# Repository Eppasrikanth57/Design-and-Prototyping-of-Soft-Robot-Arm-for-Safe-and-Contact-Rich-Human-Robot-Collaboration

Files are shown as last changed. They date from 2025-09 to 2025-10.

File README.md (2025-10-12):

# Design-and-Prototyping-of-Soft-Robot-Arm-for-Safe-and-Contact-Rich-Human-Robot-Collaboration
This repository contains the CAD designs, STL models, and embedded control code developed for my Master’s thesis at Hochschule Schmalkalden, Germany.
The project focuses on designing, building, and experimentally validating a vacuum-actuated soft robotic arm capable of safe, contact-rich human–robot collaboration.

The soft robotic arm is designed with modular flexible structures, granular-jamming-based variable stiffness, and multi-sensor feedback (force, proximity, and strain sensing). It offers a novel approach for achieving inherent safety in close human–robot interaction, aligning with the Industry 5.0 vision of human-centered manufacturing.

## 📁 Repository Structure

```bash
├── 2D Drawings/           # Technical manufacturing drawings of soft arm components  
├── 3D CAD files/          # 3D part and assembly models designed in SolidWorks 2022 and 2024  
├── Coding/                # Arduino control code for actuation, sensing, and vacuum control  
├── STL/                   # Exported STL files for 3D printing of structural components  
├── LICENSE                # MIT License for academic and research use  
└── README.md              # Project overview file
```

## 🛠️ Project Description

This thesis presents the complete design, prototyping, and validation of a motorized and vacuum-actuated soft robotic arm that dynamically changes stiffness using a Venturi-effect vacuum generator.
The system integrates force-sensing resistors (FSRs), time-of-flight (ToF) sensors, and foil strain gauges to perceive environmental interactions and respond safely to human contact.

## Key Highlights:

Vacuum-Actuated Variable Stiffness:
Uses granular jamming via a Venturi-based vacuum generator to switch between soft and rigid modes.

Soft Structure & Additive Manufacturing:
Arm links and mounts fabricated using 3D printing and elastomeric materials for modularity and flexibility.

Multi-Sensor Integration:
Embedded FSRs, ToF sensors, and strain gauges enable adaptive response and safety behavior.

Microcontroller-Based Control:
An Arduino Mega 2560 manages pneumatic valves, sensors, and control logic for real-time adaptability.

Human-Robot Safety Compliance:
Experimental results confirm impact forces remain within ISO/TS 15066 biomechanical safety limits.

## 💻 Code Overview

The Coding/ folder includes Arduino programs written for system control and sensor integration.

### Included functionalities:

Actuation control using low-power solenoid valves

Venturi vacuum generation for stiffness modulation

Real-time force and proximity sensing

Safety logic to reduce stiffness upon human approach

### Hardware interfacing includes:

Arduino Mega 2560

Festo MYH-5/3G-M5-L-LED solenoid valves

ELEGOO 5V relay module

VL53LXX-V2 ToF sensor

Force-Sensitive Resistors and Strain Gauges

## ⚙️ Experimental Validation

The system was tested through multiple experiments:

Impact Tests: Collision safety assessment with varying vacuum pressures and bead fillings.

Tension Tests: Force-displacement behavior for soft and stiff states.

Comparative Tests: Impact forces benchmarked against a UR5e collaborative robot, confirming improved safety.

The prototype demonstrated smooth transition between compliant and stiff modes, validating its effectiveness for safe, contact-rich human interaction.

## 🧩 CAD and STL Files

3D CAD files/: Solidworks models for soft arm prototypes, vacuum connectors, mounts, and baffles.

STL/: Printable versions of structural and interface components for 3D printing.

2D Drawings/: Engineering drawings with manufacturing dimensions and tolerances.

## 🔬 Applications

Human–Robot Collaboration (HRC)

Industrial manipulation and assembly

Healthcare and assistive robotics

Research and educational platforms

Service and domestic robotics

## 🧠 Research Focus

This repository supports research into:

Safe and adaptive soft robotic manipulators

Vacuum-based variable stiffness mechanisms

Multi-sensor fusion for human-aware robot control

Design methodologies for Industry 5.0 systems

## 🖌️ Licensing

This project is released under the MIT License.
All contents are free to use for academic, research, and personal learning purposes.
Commercial use requires prior written permission.

## 👨‍🎓 Author

Srikanth Reddy Eppa  
M.Eng. Mechatronics and Robotics  
Hochschule Schmalkalden, Germany

## 📧 Contact:  
For academic inquiries, feedback, or collaboration, feel free to reach out via [LinkedIn](https://www.linkedin.com/in/srikanth-reddy-eppa/) or contact through university channels.

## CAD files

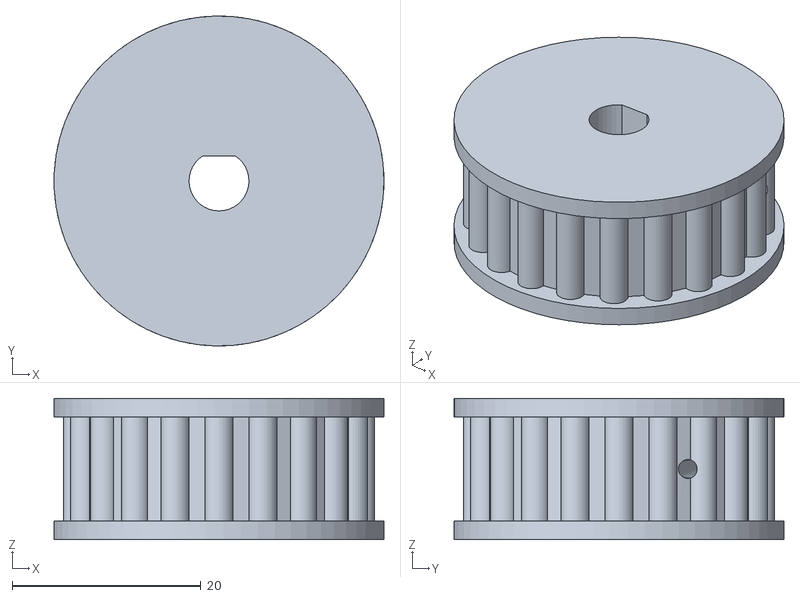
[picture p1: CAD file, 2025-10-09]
STL/Pulley.STL
35.0 x 35.0 x 15.0

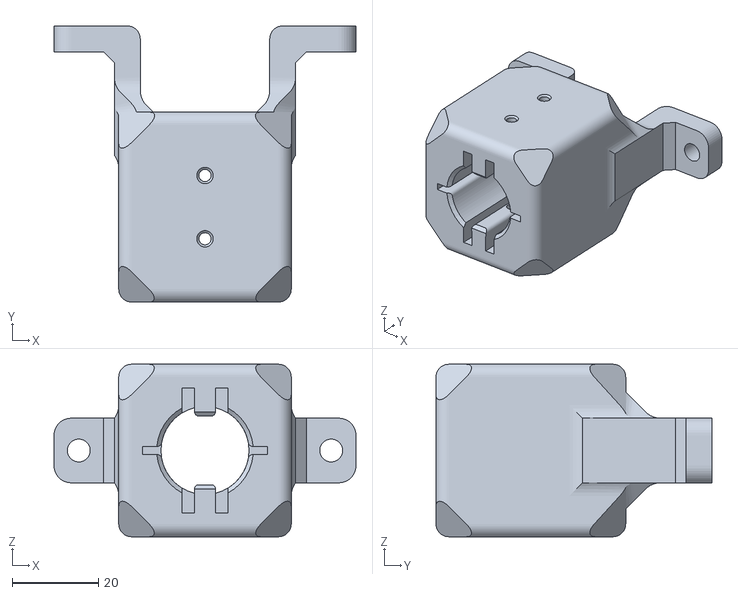
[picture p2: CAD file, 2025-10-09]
STL/Gripper mount v4.STL
70.0 x 64.0 x 40.0

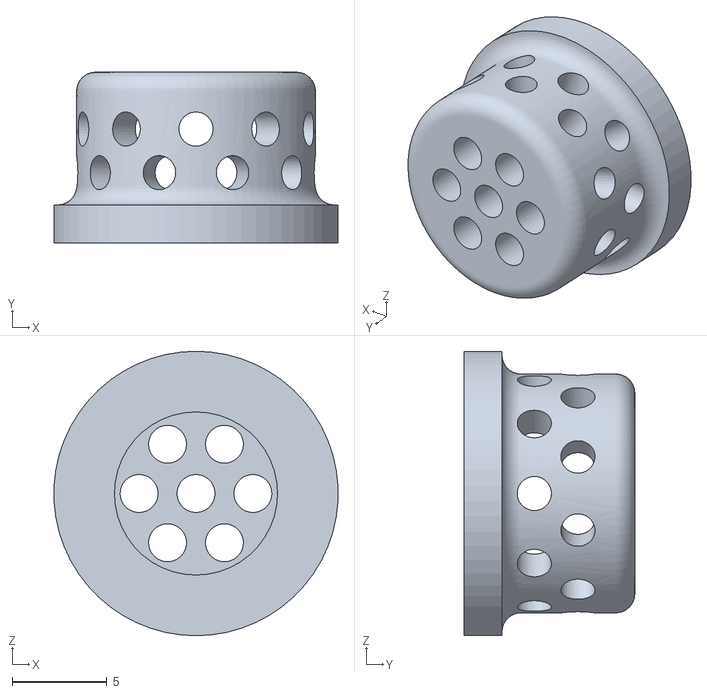
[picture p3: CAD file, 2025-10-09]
STL/Mesh.STL
15.0 x 9.00 x 15.0

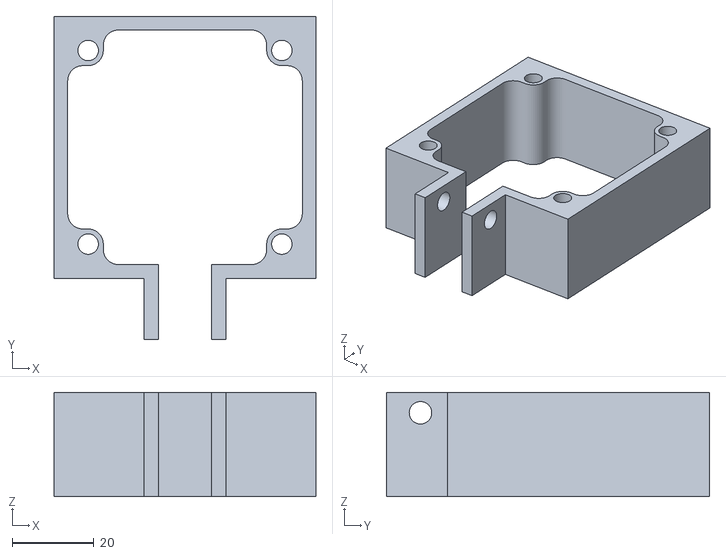
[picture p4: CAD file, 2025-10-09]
STL/Nema 23 clamp.STL
64.0 x 79.0 x 25.5

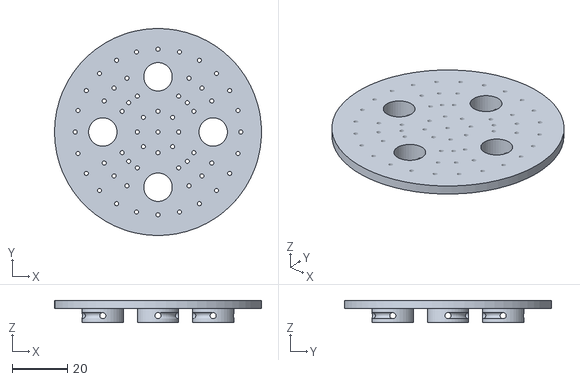
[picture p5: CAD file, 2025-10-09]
STL/Baffle plate.STL
75.0 x 75.0 x 8.00

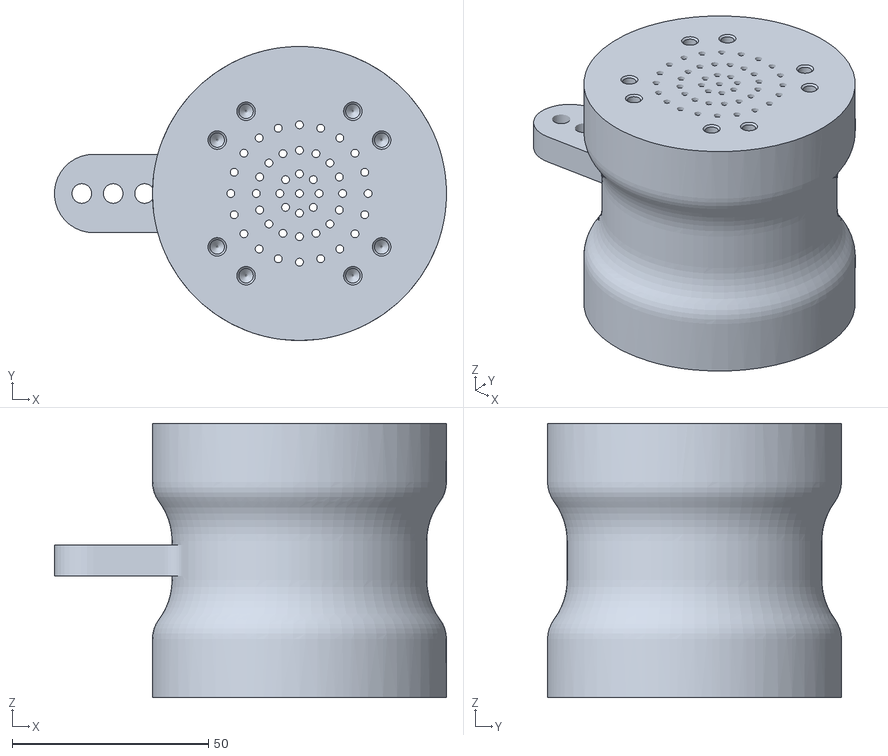
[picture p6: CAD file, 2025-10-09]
STL/Middle cylinder vacuum control test V1.STL
100.0 x 75.0 x 70.0

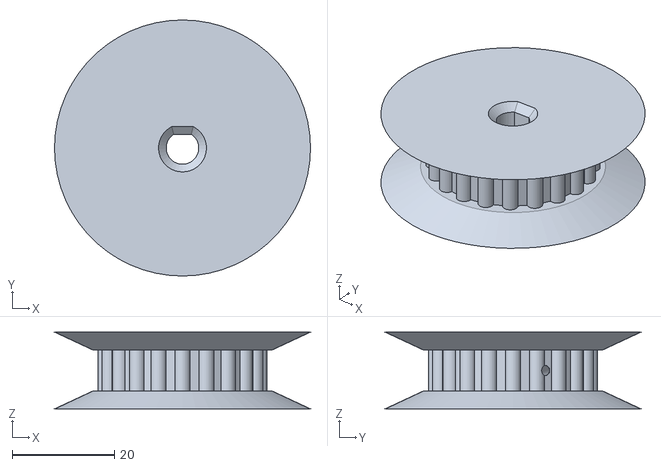
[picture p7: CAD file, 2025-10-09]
STL/Pulley V2.STL
50.0 x 50.0 x 15.0

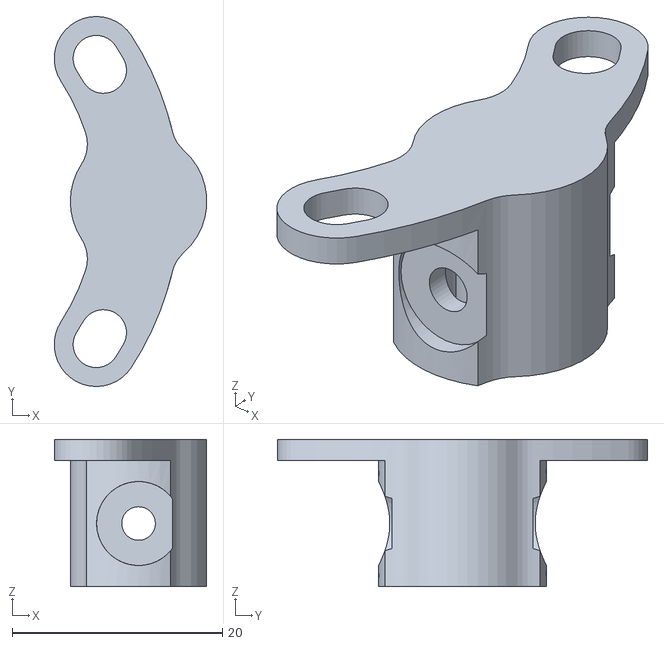
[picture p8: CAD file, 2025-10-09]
STL/Tube mount V2.STL
14.5 x 35.2 x 14.0

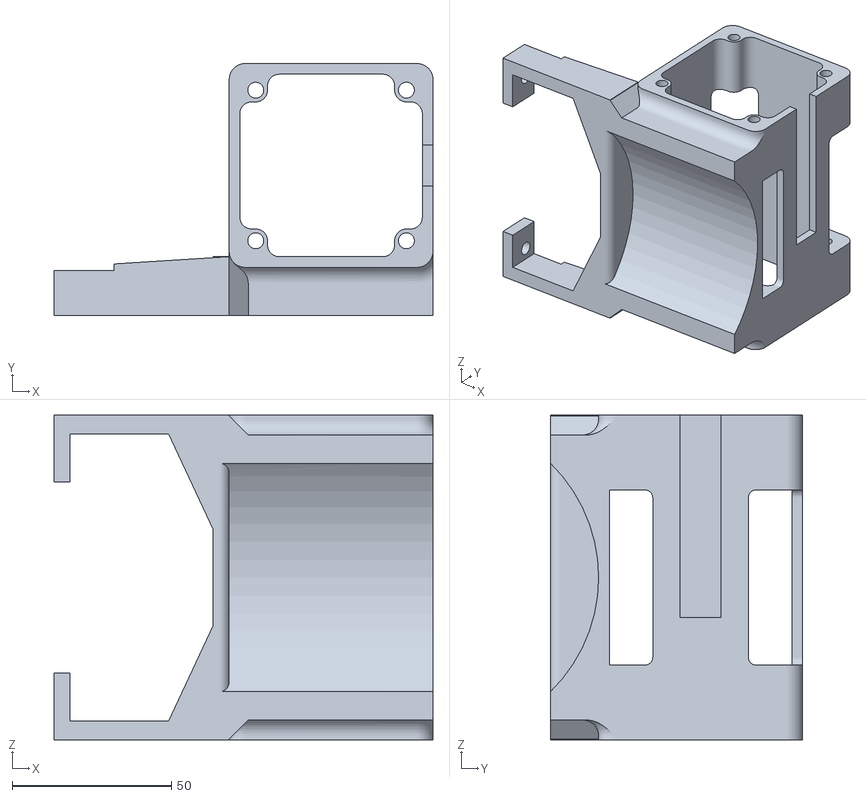
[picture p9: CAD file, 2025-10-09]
STL/2 Nema 23 clamp Actuator V2.STL
119.0 x 79.1 x 102.0

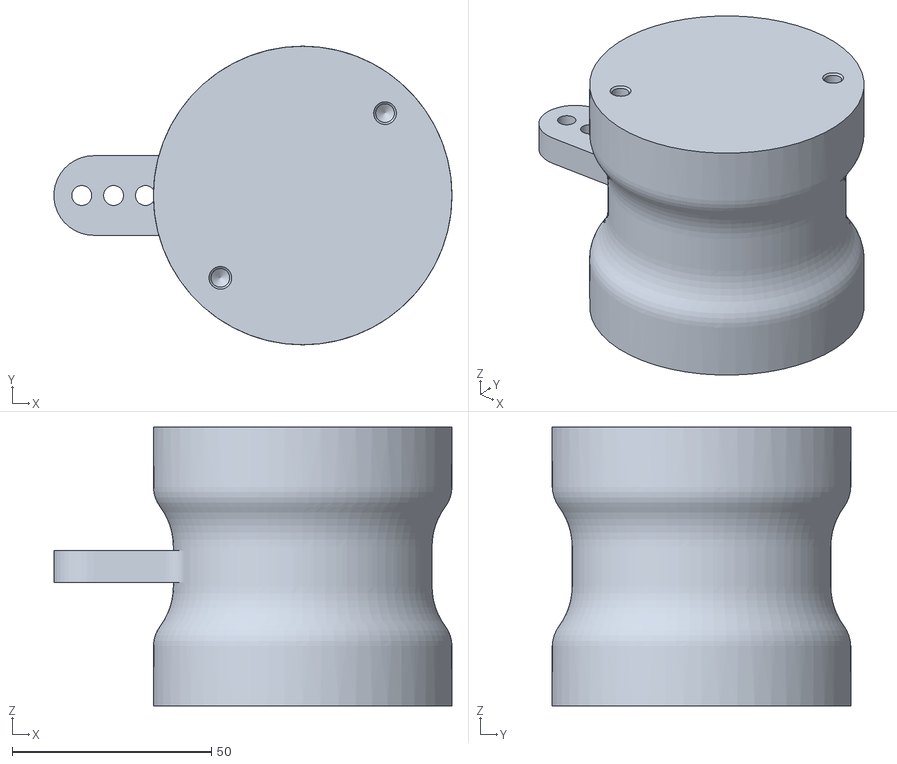
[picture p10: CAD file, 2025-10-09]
STL/Bottom cylinder vacuum control test V6.STL
100.0 x 75.0 x 70.0

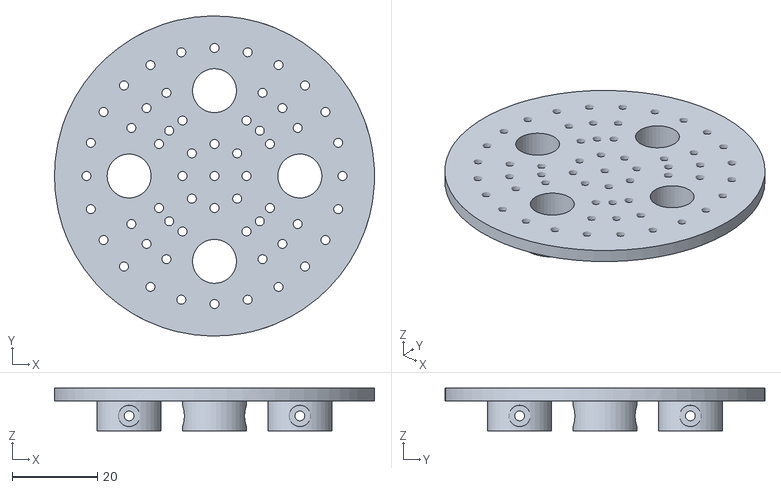
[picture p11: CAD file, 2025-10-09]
STL/Baffle plate v2.STL
75.0 x 75.0 x 10.0

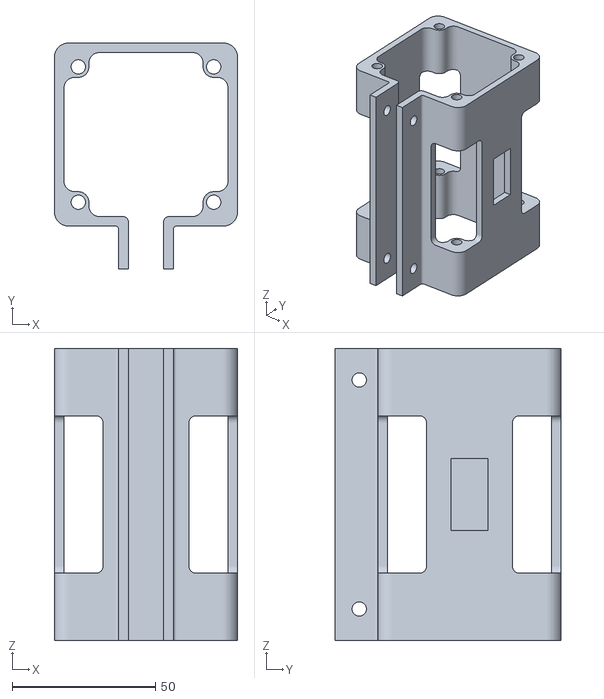
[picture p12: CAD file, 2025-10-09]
STL/2 Nema 23 clamp.STL
64.0 x 79.0 x 102.0

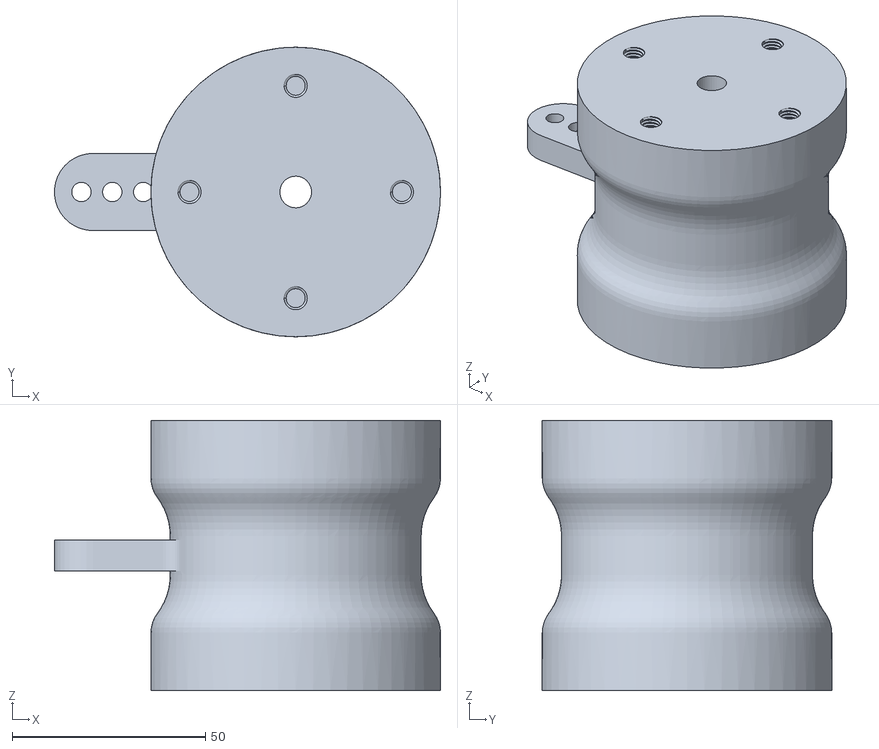
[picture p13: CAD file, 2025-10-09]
STL/Top cylinder vacuum control test V7.STL
100.0 x 75.0 x 70.0

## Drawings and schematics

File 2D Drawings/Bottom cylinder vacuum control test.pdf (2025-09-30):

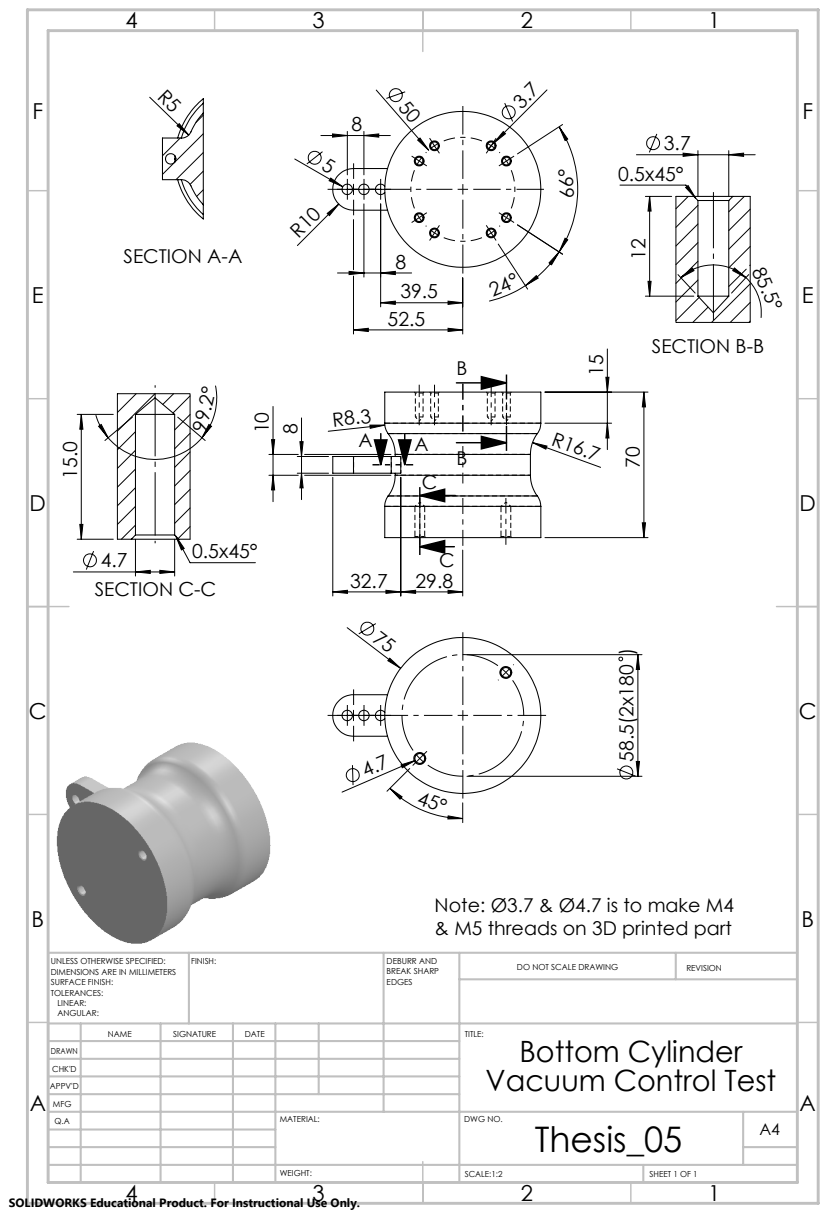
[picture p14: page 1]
SECTION A-A; SECTION B-B; SECTION C-C; FINISH:; DEBURR AND; BREAK SHARP; DO NOT SCALE DRAWING; REVISION; SCALE:1:2; SHEET 1 OF 1

Note: Ø3.7 & Ø4.7 is to make M4
& M5 threads on 3D printed part

UNLESS OTHERWISE SPECIFIED:
DIMENSIONS ARE IN MILLIMETERS
SURFACE FINISH:
TOLERANCES:
LINEAR:
ANGULAR:

NAME | SIGNATURE | DATE | | | | TITLE: Bottom Cylinder Vacuum Control Test

DRAWN
CHK'D
APPV'D
MFG
Q.A | | | | MATERIAL: | DWG NO. Thesis_05 | A4

SOLIDWORKS Educational Product. For Instructional Use Only.

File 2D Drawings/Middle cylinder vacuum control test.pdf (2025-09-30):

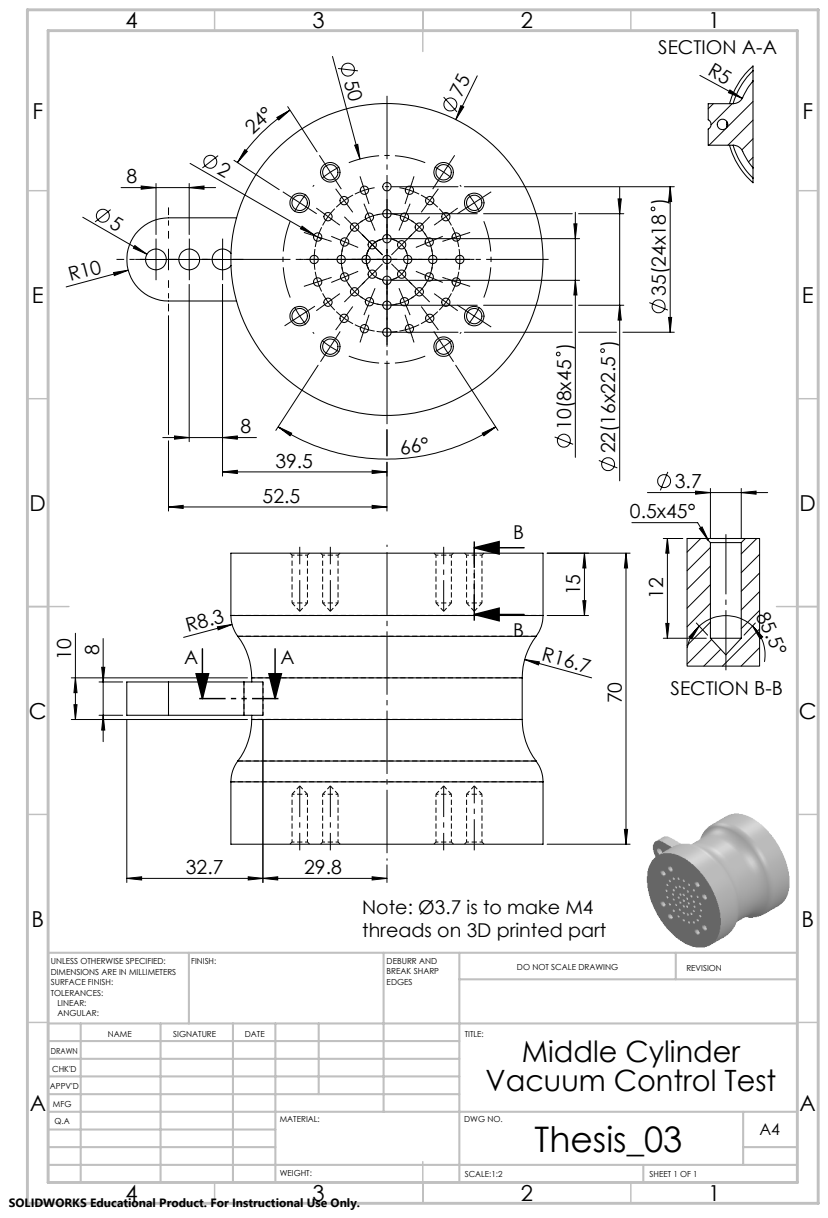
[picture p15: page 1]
SECTION A-A; SECTION B-B; FINISH:; DEBURR AND; BREAK SHARP; DO NOT SCALE DRAWING; REVISION; SCALE:1:2; SHEET 1 OF 1

Note: Ø3.7 is to make M4
threads on 3D printed part

UNLESS OTHERWISE SPECIFIED:
DIMENSIONS ARE IN MILLIMETERS
SURFACE FINISH:
TOLERANCES:
LINEAR:
ANGULAR:

NAME | SIGNATURE | DATE | | | | TITLE: Middle Cylinder Vacuum Control Test

DRAWN
CHK'D
APPV'D
MFG
Q.A | | | | MATERIAL: | DWG NO. Thesis_03 | A4

SOLIDWORKS Educational Product. For Instructional Use Only.

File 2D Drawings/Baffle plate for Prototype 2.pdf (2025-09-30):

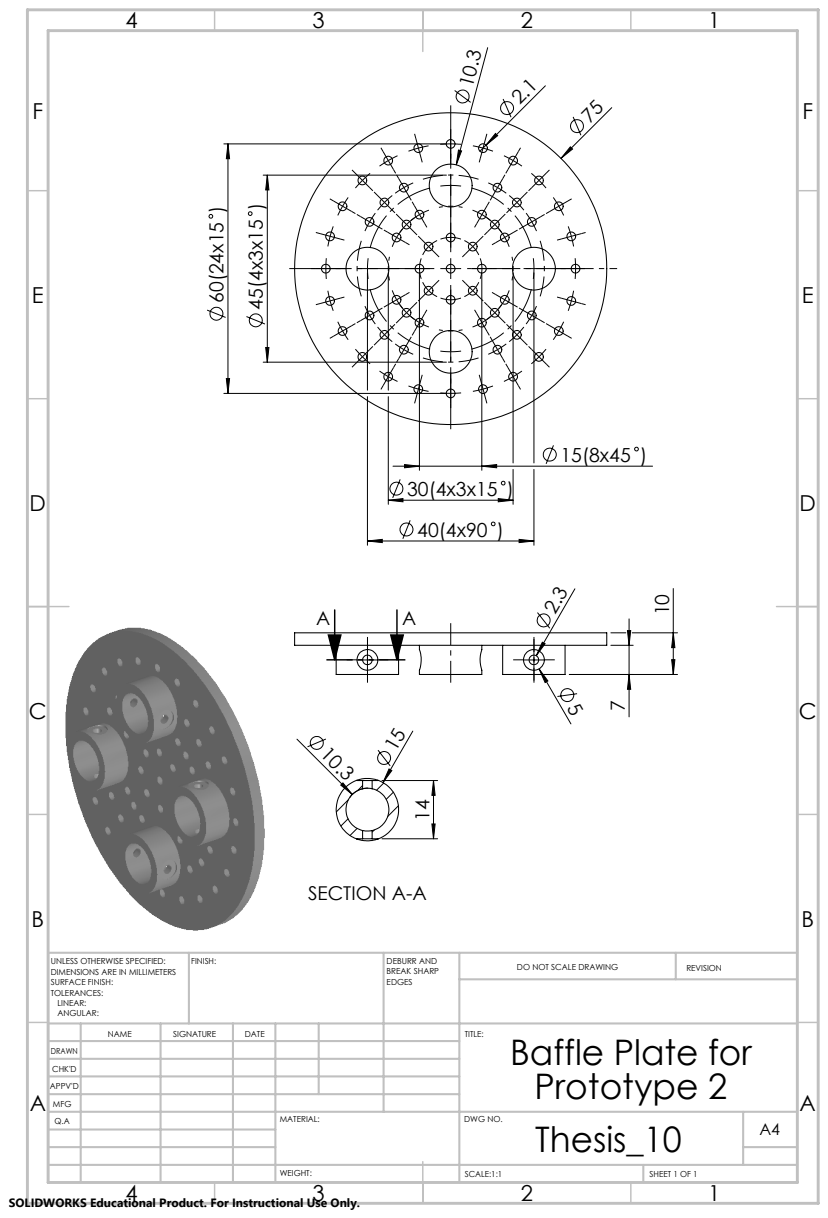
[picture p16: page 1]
SECTION A-A; FINISH:; DEBURR AND; BREAK SHARP; DO NOT SCALE DRAWING; REVISION; SCALE:1:1; SHEET 1 OF 1

UNLESS OTHERWISE SPECIFIED:
DIMENSIONS ARE IN MILLIMETERS
SURFACE FINISH:
TOLERANCES:
LINEAR:
ANGULAR:

NAME | SIGNATURE | DATE | | | | TITLE: Baffle Plate for Prototype 2

DRAWN
CHK'D
APPV'D
MFG
Q.A | | | | MATERIAL: | DWG NO. Thesis_10 | A4

SOLIDWORKS Educational Product. For Instructional Use Only.

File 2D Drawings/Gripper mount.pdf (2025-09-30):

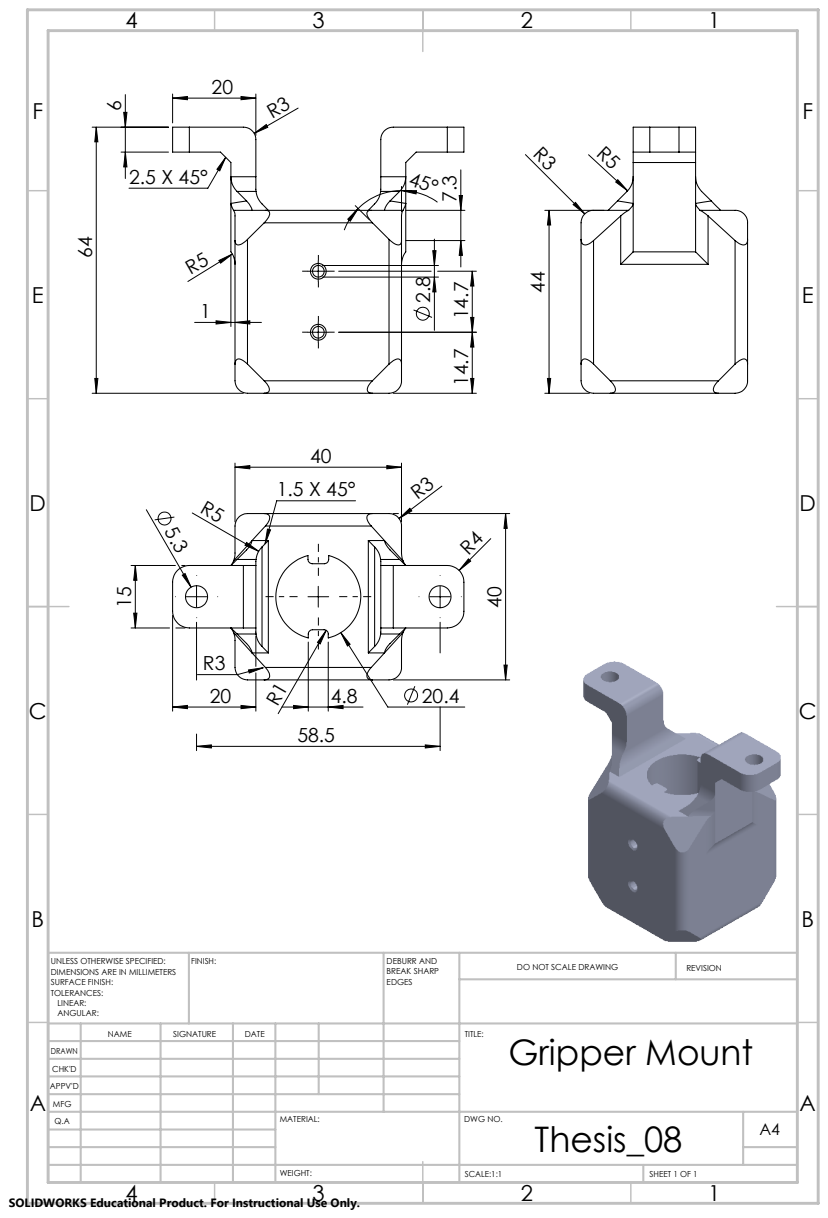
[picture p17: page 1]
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

UNLESS OTHERWISE SPECIFIED:
DIMENSIONS ARE IN MILLIMETERS
SURFACE FINISH:
TOLERANCES:
LINEAR:
ANGULAR:

NAME | SIGNATURE | DATE | | | | TITLE: Gripper Mount

DRAWN
CHK'D
APPV'D
MFG
Q.A | | | | MATERIAL: | DWG NO. Thesis_08 | A4

SOLIDWORKS Educational Product. For Instructional Use Only.

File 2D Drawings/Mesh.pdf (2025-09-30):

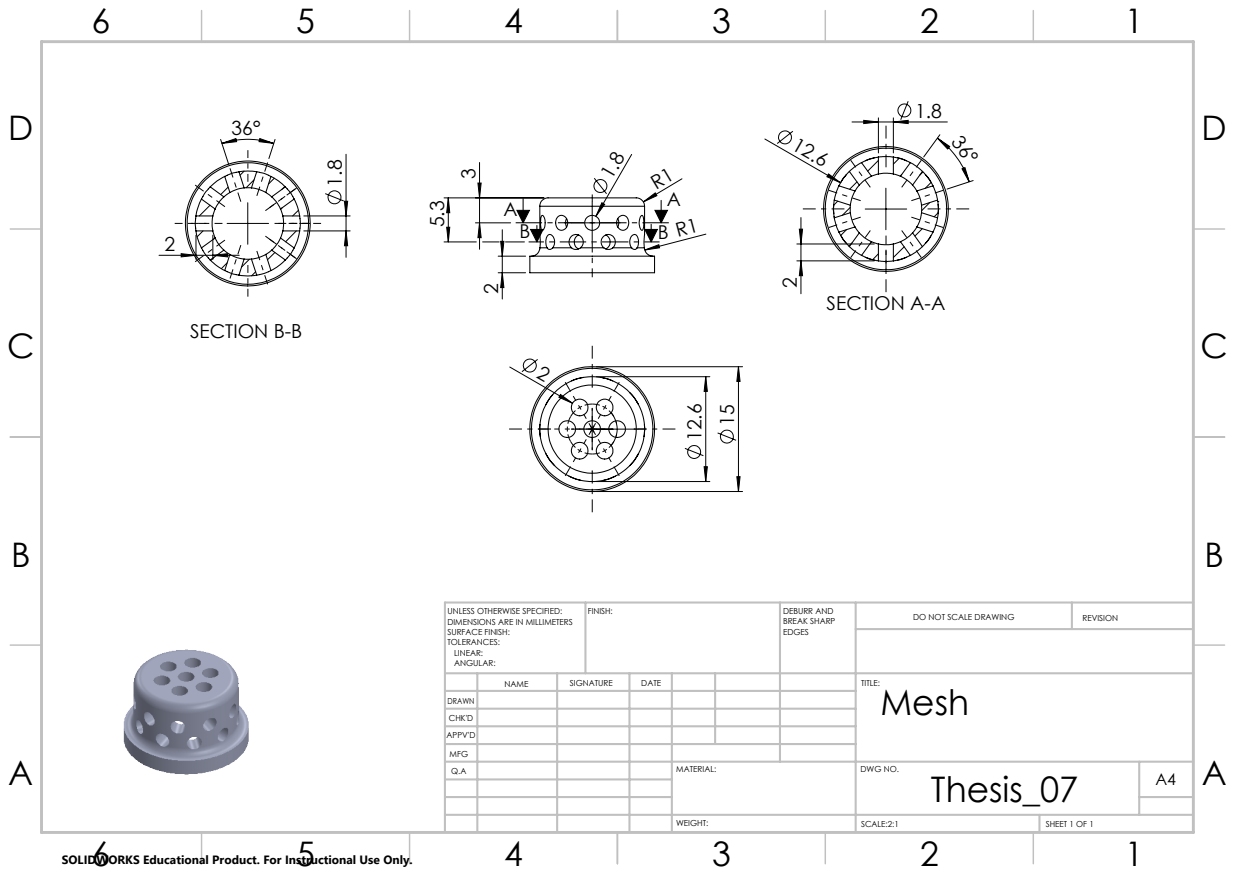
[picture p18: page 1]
SECTION A-A; SECTION B-B; FINISH:; DEBURR AND; BREAK SHARP; DO NOT SCALE DRAWING; REVISION; SCALE:2:1; SHEET 1 OF 1

UNLESS OTHERWISE SPECIFIED:
DIMENSIONS ARE IN MILLIMETERS
SURFACE FINISH:
TOLERANCES:
LINEAR:
ANGULAR:

NAME | SIGNATURE | DATE | | | | TITLE: Mesh

DRAWN
CHK'D
APPV'D
MFG
Q.A | | | | MATERIAL: | DWG NO. Thesis_07 | A4

SOLIDWORKS Educational Product. For Instructional Use Only.

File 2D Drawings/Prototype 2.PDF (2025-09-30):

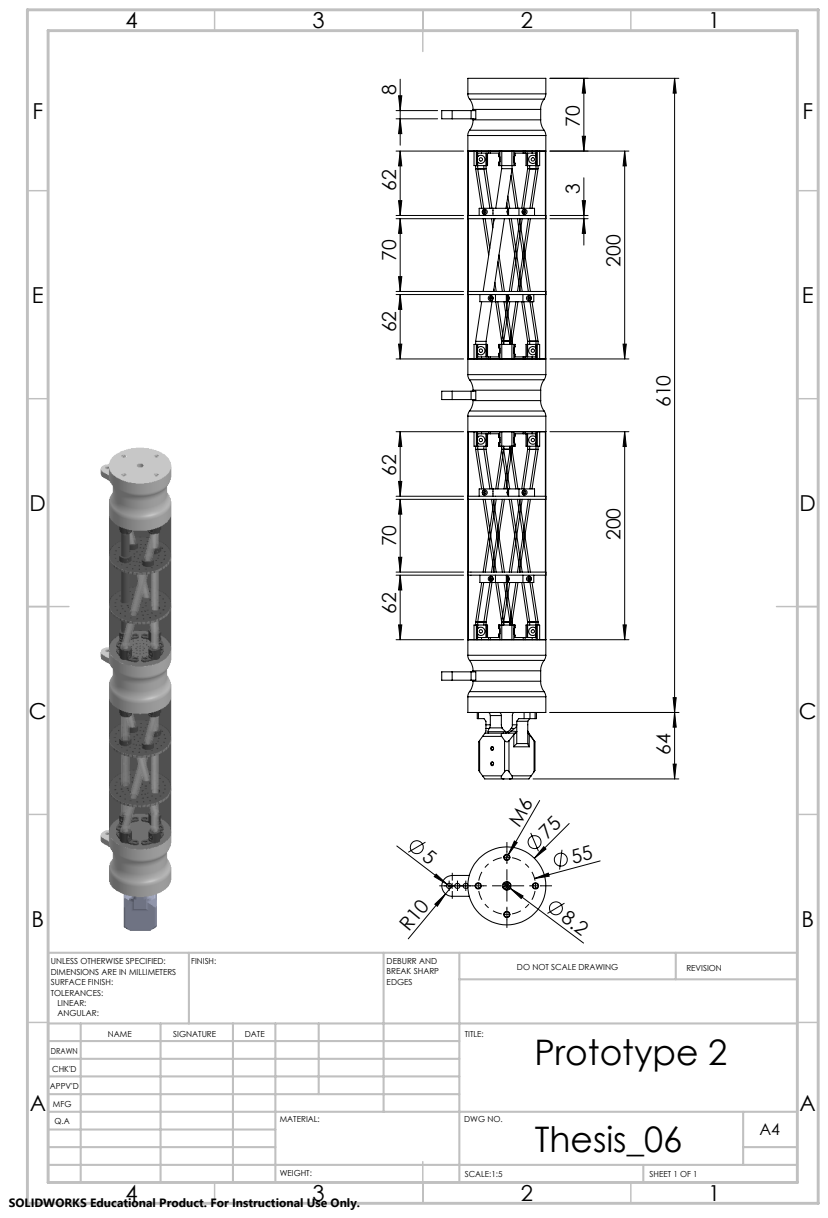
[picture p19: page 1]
FINISH:; DEBURR AND; BREAK SHARP; DO NOT SCALE DRAWING; REVISION; SCALE:1:5; SHEET 1 OF 1

UNLESS OTHERWISE SPECIFIED:
DIMENSIONS ARE IN MILLIMETERS
SURFACE FINISH:
TOLERANCES:
LINEAR:
ANGULAR:

NAME | SIGNATURE | DATE | | | | TITLE: Prototype 2

DRAWN
CHK'D
APPV'D
MFG
Q.A | | | | MATERIAL: | DWG NO. Thesis_06 | A4

SOLIDWORKS Educational Product. For Instructional Use Only.

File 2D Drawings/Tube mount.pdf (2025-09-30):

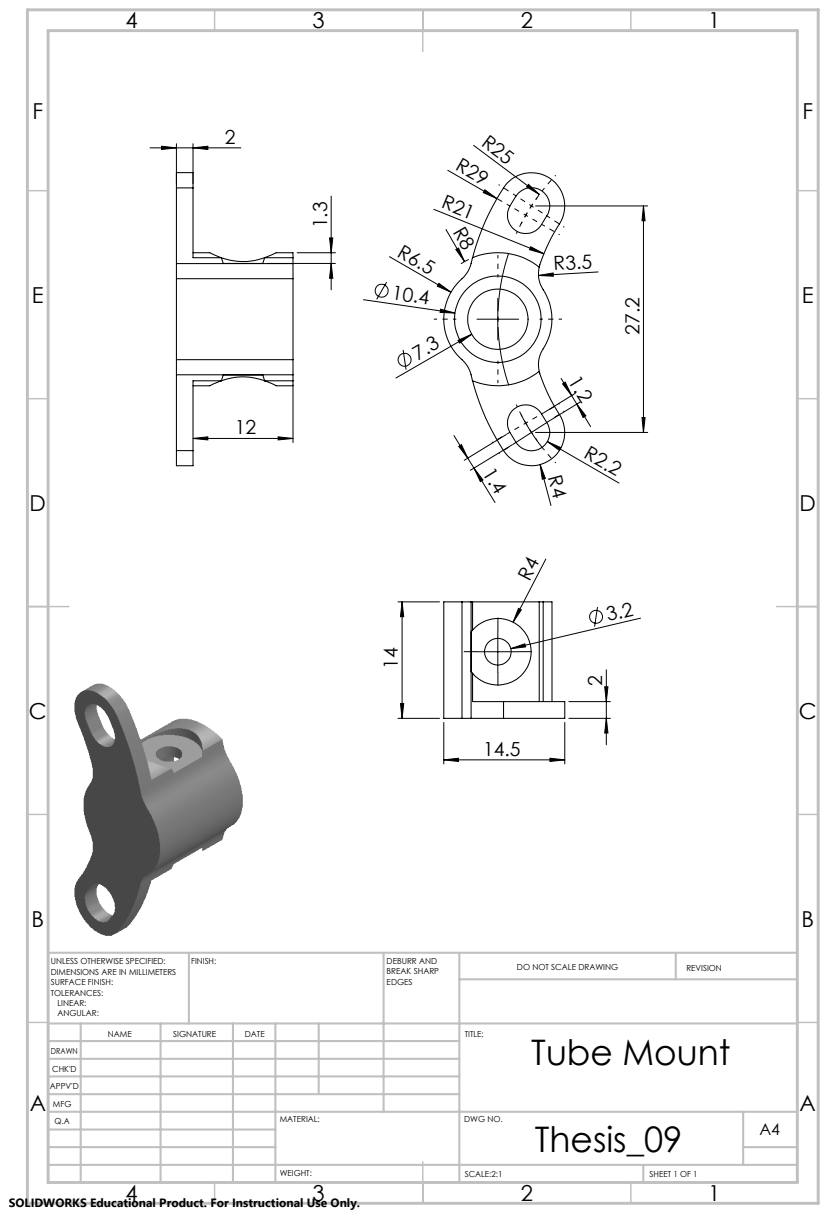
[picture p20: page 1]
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

UNLESS OTHERWISE SPECIFIED:
DIMENSIONS ARE IN MILLIMETERS
SURFACE FINISH:
TOLERANCES:
LINEAR:
ANGULAR:

NAME | SIGNATURE | DATE | | | | TITLE: Tube Mount

DRAWN
CHK'D
APPV'D
MFG
Q.A | | | | MATERIAL: | DWG NO. Thesis_09 | A4

SOLIDWORKS Educational Product. For Instructional Use Only.

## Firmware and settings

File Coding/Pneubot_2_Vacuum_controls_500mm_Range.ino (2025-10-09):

#include <Adafruit_VL53L0X.h>

Adafruit_VL53L0X lox = Adafruit_VL53L0X();

// Pins
const int buttonPin = 13;
const int relayPin2 = 5;
const int relayPin1 = 6; 
const int stepPin1 = 30;
const int dirPin1 = 31;

// Sensor averaging
const int MAX_DATA = 10;
int data[MAX_DATA] = {};
int readDataIndex = 0;
bool bufferFull = false;

// Relay control
const int threshold = 500;
int smoothedDistance = 1000;  // default far

// Variable to track vacuum state
bool vacuumState = true; // vacuum should start as ON

// Motor control
const int stepsPerRevolution = 800;
const int totalStepsPerCycle = stepsPerRevolution * 2; // 5 rotations
unsigned long stepInterval = 400; // microseconds between steps (adjust for speed)

bool motorActive = false;
bool isPaused = false;
bool direction = false; // Start with ACW
unsigned long lastStepTime = 0;
unsigned long pauseStartTime = 0;
unsigned long pauseDuration = 2000;

int stepCount = 0;
int completedCycles = 0;
const int maxCycles = 2; // Two cycles to do ACW then CW

// Setup
void setup() {
  Serial.begin(115200);
  
  pinMode(buttonPin, INPUT);
  pinMode(relayPin2, OUTPUT);
  pinMode(relayPin1, OUTPUT);
  pinMode(stepPin1, OUTPUT);
  pinMode(dirPin1, OUTPUT);
  
  // Vacuum ON initially
  digitalWrite(relayPin2, LOW);
  digitalWrite(relayPin1, LOW);
  vacuumState = true;

  // Set initial motor direction (LOW = ACW, HIGH = CW)
  digitalWrite(dirPin1, direction ? HIGH : LOW);
  
  // Initialize sensor data array
  for (int i = 0; i < MAX_DATA; i++) {
    data[i] = 1000;
  }
  
  Serial.println("Starting up...");
  
  if (!lox.begin()) {
    Serial.println("Failed to initialize VL53L0X!");
    while (1);
  }
  
  Serial.println("System ready - Press button to start motor");
}

// Read sensor and average
int getSmoothedDistance() {
  VL53L0X_RangingMeasurementData_t measure;
  lox.rangingTest(&measure, false);

  int currentReading = measure.RangeMilliMeter;

  // Accept statuses 0 (good), 1-2 (valid but less ideal)
  if (measure.RangeStatus <= 2) {
    data[readDataIndex] = currentReading;
    readDataIndex = (readDataIndex + 1) % MAX_DATA;
    if (readDataIndex == 0) bufferFull = true;
  } else {
    // Don't include bad readings in average
    return smoothedDistance;
  }

  // Compute average excluding invalid data
  int sum = 0, count = 0;
  int loopLimit = bufferFull ? MAX_DATA : readDataIndex;
  for (int i = 0; i < loopLimit; i++) {
    if (data[i] > 0) {
      sum += data[i];
      count++;
    }
  }

  int average = (count > 0) ? sum / count : smoothedDistance;

  Serial.print("Raw Distance: ");
  Serial.print(currentReading);
  Serial.print(" | Smoothed: ");
  Serial.println(average);

  return average;
}

void resetMotorCycles() {
    completedCycles = 0;  // Reset the number of completed cycles
    direction = false;    // Reset direction to default (ACW)
    Serial.println("Motor cycles reset");
}

void loop() {
  // Handle ToF sensor and vacuum control
  static unsigned long lastSensorRead = 0;
  if (millis() - lastSensorRead >= 50) {
    lastSensorRead = millis();
    int dist = getSmoothedDistance();
    
    if (dist > 0) {
      smoothedDistance = dist;
      
      // Object detected, turn vacuum off
      if (smoothedDistance < threshold && vacuumState) {
        digitalWrite(relayPin2, HIGH);
        digitalWrite(relayPin1, HIGH);
        vacuumState = false;
        Serial.println("Object detected - Vacuum OFF");
      } 
      // No object, turn vacuum on
      else if (smoothedDistance >= threshold && !vacuumState) {
        digitalWrite(relayPin2, LOW);
        digitalWrite(relayPin1, LOW);
        vacuumState = true;
        Serial.println("No object - Vacuum ON");
      }
    }
  }

  // Check button press to start motor sequence
  static bool lastButtonState = false;
  bool currentButtonState = digitalRead(buttonPin);
  
  if (currentButtonState && !lastButtonState && !motorActive && !isPaused && completedCycles < maxCycles) {
    // Button pressed, start motor
    motorActive = true;
    stepCount = 0;
    digitalWrite(dirPin1, direction ? HIGH : LOW);
    Serial.print("Motor started - Direction: ");
    Serial.println(direction ? "CW" : "ACW");
  }
  lastButtonState = currentButtonState;

  // Motor stepping logic - simplified for reliability
  if (motorActive) {
    unsigned long currentMicros = micros();
    if (currentMicros - lastStepTime >= stepInterval) {
      lastStepTime = currentMicros;
      
      // Generate step pulse
      digitalWrite(stepPin1, HIGH);
      //delayMicroseconds(5); // Ensure pulse is seen by driver
      // Replace delayMicroseconds(5) with micros() implementation
      unsigned long pulseStartTime = micros();
      while (micros() - pulseStartTime < 5) {
        // Empty loop to wait for 5 microseconds
      }
      digitalWrite(stepPin1, LOW);
      
      stepCount++;
      
      // Progress reporting
      if (stepCount % 800 == 0) {
        Serial.print("Steps: ");
        Serial.print(stepCount);
        Serial.print("/");
        Serial.println(totalStepsPerCycle);
      }

      // Check if cycle complete
      if (stepCount >= totalStepsPerCycle) {
        motorActive = false;
        isPaused = true;
        pauseStartTime = millis();
        Serial.println("Motor sequence completed, pausing");
      }
    }
  }

  // Handle pausing between cycles
  if (isPaused && (millis() - pauseStartTime >= pauseDuration)) {
    isPaused = false;
    completedCycles++;
    
    if (completedCycles < maxCycles) {
      // Start next cycle
      direction = !direction;  // Reverse direction
      motorActive = true;
      stepCount = 0;
      digitalWrite(dirPin1, direction ? HIGH : LOW);
      Serial.print("Starting cycle ");
      Serial.print(completedCycles + 1);
      Serial.print(" - Direction: ");
      Serial.println(direction ? "CW" : "ACW");
    } else {
      Serial.println("All motor sequences completed");
  
  
    
    // Auto-reset after completion (add these lines)
    //delay(1000);  // Wait 1 seconds before resetting
    resetMotorCycles();  // Reset cycles back to zero
    Serial.println("Motor cycles auto-reset. Ready for next button press.");
  }
}
}

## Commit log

2025-09-30 Create sample
2025-09-30 Create STL files
